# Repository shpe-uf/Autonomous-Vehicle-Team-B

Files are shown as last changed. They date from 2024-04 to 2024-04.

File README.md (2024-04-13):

# Autonomous-Vehicle-Team-B

Introducing our high-performance autonomous RC car, masterfully piloted by the iconic Dominic Toretto. Engineered for versatility, it thrives on diverse terrains with advanced obstacle avoidance, sign detection, and lane keeping. At its core, powerful motors and a sophisticated turning mechanism ensure dynamic mobility, while a 12V battery and Raspberry Pi brain equip it with formidable power and intelligence. This vehicle isn't just about getting from A to B; it's about the journey in between, redefining what it means to drive autonomously.

## Prerequisites

Before you can run this project, you'll need the following installed:

- Python 3.6 or higher
- OpenCV-Python
- picamera2 (specific to Raspberry Pi OS)
- RPi.GPIO (specific to Raspberry Pi)
- asyncio library (should be included with Python 3.6+)

You can install Python from [the official website](https://www.python.org/downloads/).

## Installation

1. **OpenCV-Python**: Install OpenCV for Python by running:

   ```
   pip install opencv-python
   ```

2. **picamera2**: For Raspberry Pi, install the picamera2 library using:

   ```
   sudo apt-get update
   sudo apt-get install python3-picamera2
   ```

3. **RPi.GPIO**: This should come pre-installed with Raspberry Pi OS. If you need to install it, use:

   ```
   sudo apt-get install python3-rpi.gpio
   ```

## Training Cascade Classifiers

Training your own cascade classifiers with OpenCV involves several steps. You will need a set of positive images (images of your object) and negative images (images without your object). Follow these steps:

1. **Collect Images**: Gather a dataset of positive and negative images. Positive images should contain the object you want to detect, and negative images should not.

2. **Annotation**: Use an annotation tool to mark the object in each positive image. One such tool is `labelImg`.

   - Installation: `pip install labelImg`
   - Usage: Run `labelImg`, open your dataset, and start annotating.

3. **Create Samples**: Use OpenCV's `opencv_createsamples` utility to create a vector file from your annotated positive images.

   ```
   opencv_createsamples -info annotations.txt -num 1000 -w 20 -h 20 -vec positives.vec
   ```

4. **Train Cascade**: With the positive vector file and the collection of negative images, you can train the cascade classifier.

   ```
   opencv_traincascade -data cascade_directory -vec positives.vec -bg negatives.txt -numPos 800 -numNeg 400 -numStages 10 -w 20 -h 20
   ```

   Adjust the `numPos`, `numNeg`, and `numStages` parameters based on your dataset.

## Wiring Instructions

The code provided controls a Raspberry Pi-based robot with obstacle detection, line tracking, and basic navigation features. Here's a summary of the wiring based on the GPIO pins defined in your code:

- **Motors**:
  - `motorIn1`, `motorIn2`: Connect to the left motor.
  - `motorIn3`, `motorIn4`: Connect to the right motor.
  - `enL`, `enR`: Connect to the enable pins on your motor driver to control speed.

- **LEDs**:
  - `LEFT`, `RIGHT`: Connect to LEDs that indicate turning direction.

- **Ultrasonic Sensor**:
  - `TRIG`: Connect to the trigger pin.
  - `ECHO`: Connect to the echo pin.

## Project Files Overview

- **`Camera_Drive_Merge.py`**: This is the final competition code and the main file to run everything. It integrates camera-based signal detection with driving functions.
- **`async.py`**: Contains the driving function for the first competition, which is focused on basic driving without camera integration.
- **`signal_detection2.py`**: Used for testing multiple cascades for image detection. It allows you to test the performance of different cascades in recognizing various signals.
- **`signal_detection1.py`**: Designed for testing a single cascade. This script is useful for focused testing on one particular type of signal.
- **XML Files**: These are the cascade files used for image detection. They should be trained as described in the "Training Cascade Classifiers" section and placed in the same directory as your Python scripts for the project.
- **Assembly Mounts**: This folder includes all the 3D-printed mounts designed for securing the vehicle's sensors. It features detailed CAD drawings and specifications essential for proper mount fabrication and sensor integration. 

Please make sure to place all your scripts and XML files in the same directory and run `Camera_Drive_Merge.py` as the main script to start the project.

## Advice for Future Teams

### Asynchronous Programming
Incorporate asynchronous programming to manage concurrent tasks such as sensor readings and motor control. Understanding and using Python's `asyncio` library can significantly enhance the efficiency of your code.

### GPIO and Hardware Interfacing
Gain a clear understanding of Raspberry Pi's GPIO for connecting components like motors and sensors. Ensure correct setup and initialization to avoid unexpected behavior or damage.

### Sensor Integration
Properly integrate and process data from sensors like ultrasonic and line tracking sensors. Implementing filtering and debouncing can improve the reliability of sensor data interpretation.

## Our Trials and Tribulations

### Prototyping Delays
Our project faced setbacks due to delays in 3D printing components, which hindered the coding team's ability to test and debug the system. Future teams should aim to have prototypes ready early on, allowing for simultaneous development and testing by both the mechanical and coding teams. Temporary mounts can be invaluable for this iterative testing process.

### Hardware Challenges
We encountered a significant issue when our camera unexpectedly short-circuited, which went unnoticed until our second competition. This underscored the importance of thoroughly testing each hardware component independently to ensure they are functioning correctly. Pay attention to signs of malfunction, such as components running hotter than usual, which could indicate underlying problems.

### Communication and Commitment
Despite the challenges we faced, strong communication and dedication among team members were key to navigating through difficulties. It's crucial to remain committed and work collaboratively, especially when encountering obstacles. Our ability to stay devoted and allocate the necessary time to address issues played a significant role in overcoming the hurdles we encountered.

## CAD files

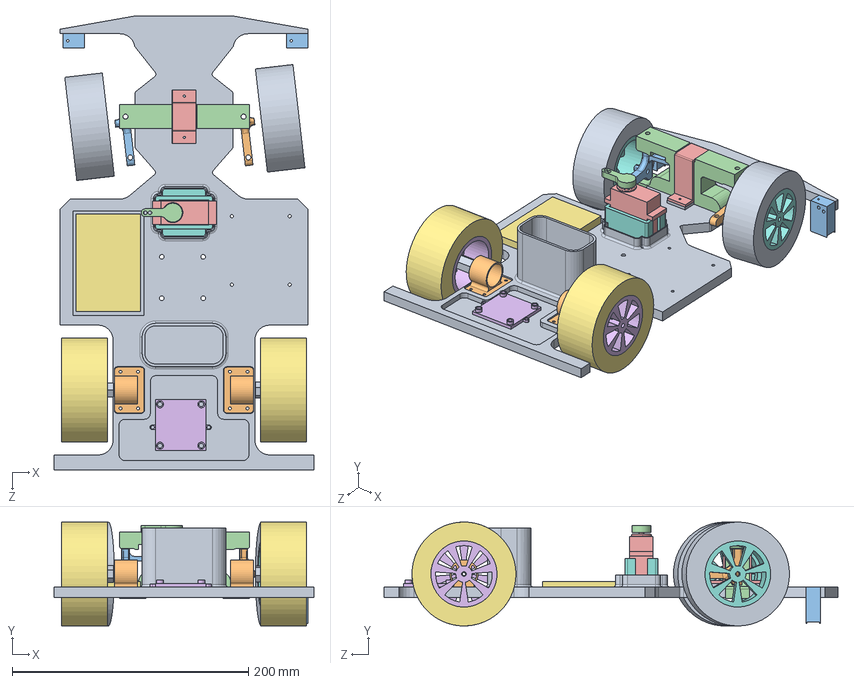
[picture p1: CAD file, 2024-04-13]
Assembly Mounts/Assembly 2.SLDASM
220.0 x 88.0 x 384.4 mm
Frame #2
Servo Motor
Breadboard
motor driver mount
ClampsReal
Steering Frame
Wheel Pivot (With mount)
Wheel Pivot (without mount)
FrontTireSimple x 2
FrontWheelSimple x 2
RearTireSimple x 2
RearWheelSimple x 2
Copy of Servo Motor
Directional pivot (1)
marley.mount.IR_sensor (1) x 2
DC w torque motor mount x 2
wheel rod with torque x 2

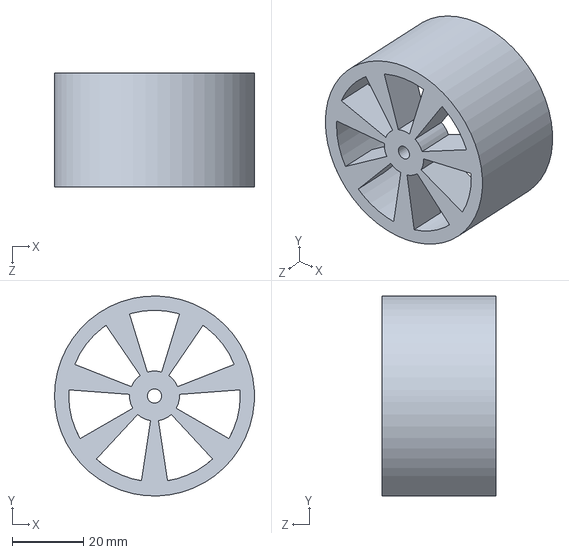
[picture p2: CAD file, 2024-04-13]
Assembly Mounts/FrontWheelSimple.SLDPRT
56.0 x 56.0 x 32.0 mm

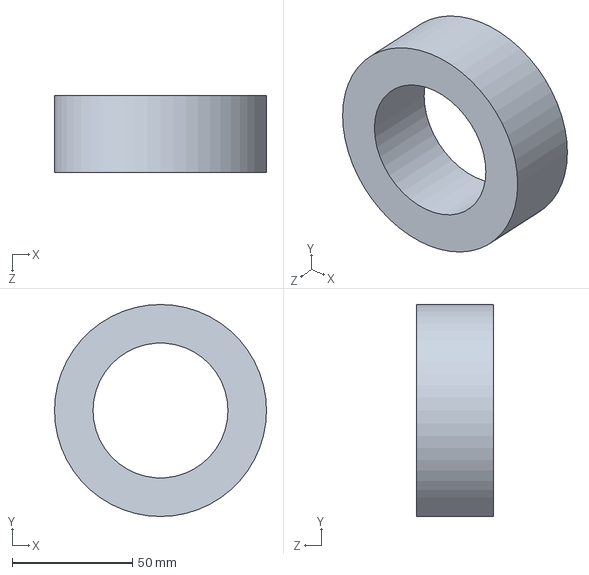
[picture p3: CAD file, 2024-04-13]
Assembly Mounts/FrontTireSimple.SLDPRT
88.0 x 88.0 x 32.0 mm

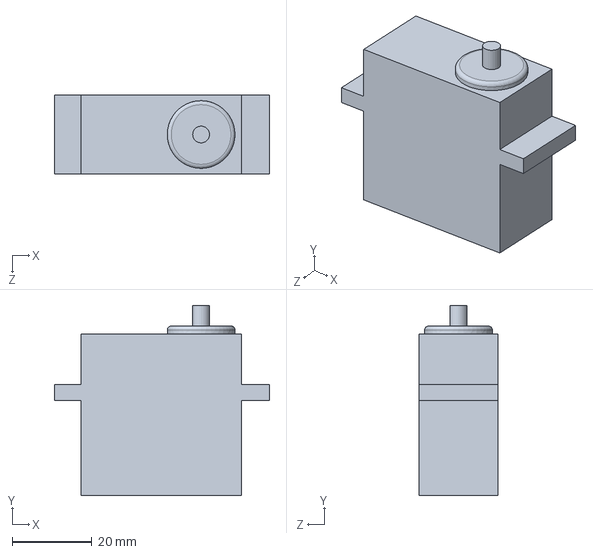
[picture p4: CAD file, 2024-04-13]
Assembly Mounts/Copy of Servo Motor.SLDPRT
54.0 x 47.8 x 19.8 mm

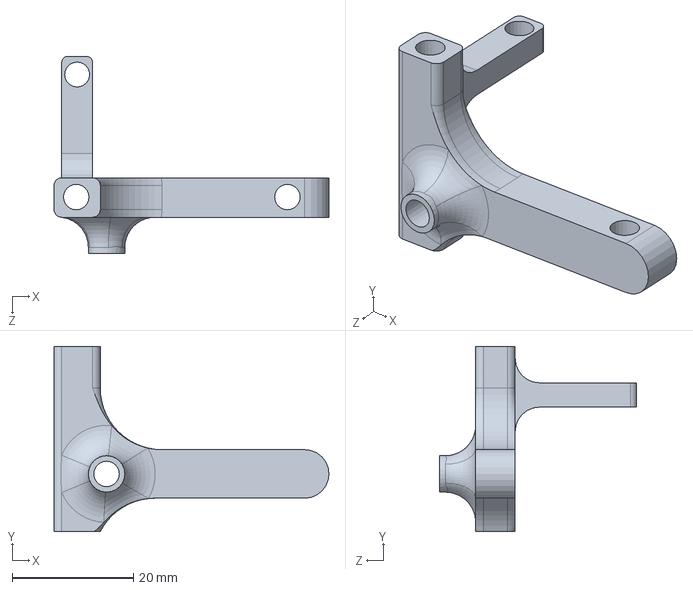
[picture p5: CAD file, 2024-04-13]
Assembly Mounts/Wheel Pivot (With mount).SLDPRT
45.3 x 30.5 x 32.5 mm

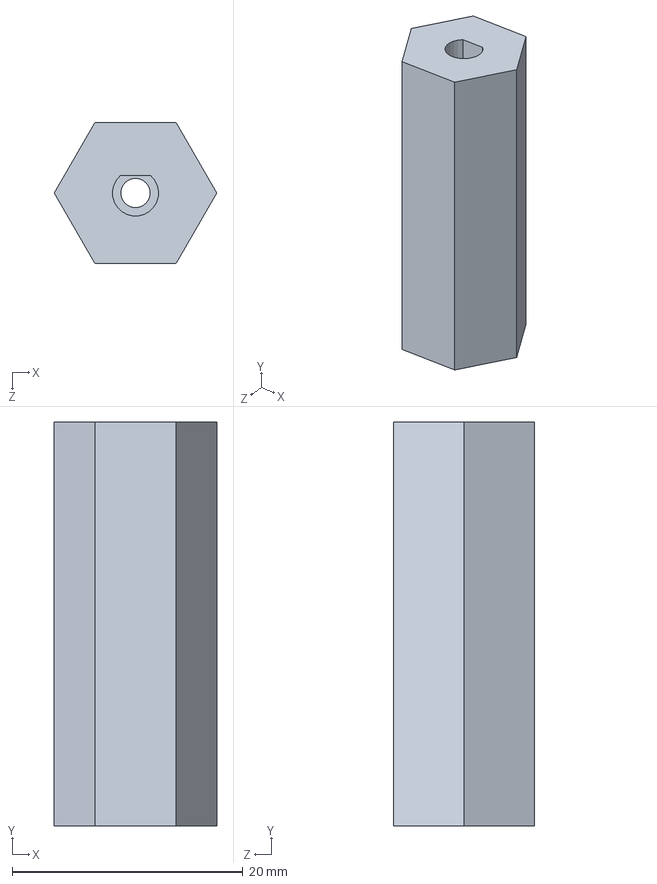
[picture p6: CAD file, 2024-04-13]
Assembly Mounts/wheel rod with torque.SLDPRT
14.1 x 35.0 x 12.2 mm

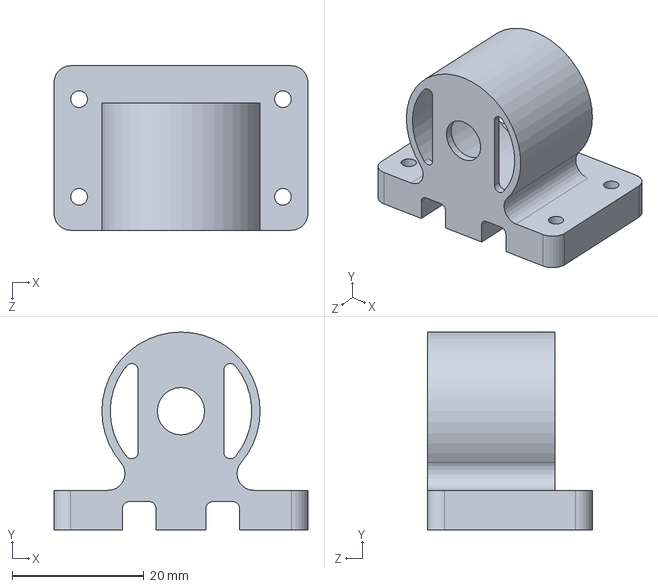
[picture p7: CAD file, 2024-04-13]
Assembly Mounts/DC w torque motor mount.SLDPRT
38.6 x 30.1 x 25.0 mm

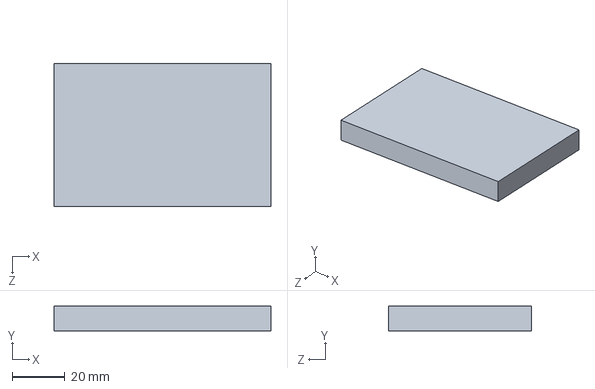
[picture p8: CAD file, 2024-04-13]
Assembly Mounts/Breadboard.SLDPRT
82.5 x 9.50 x 54.2 mm

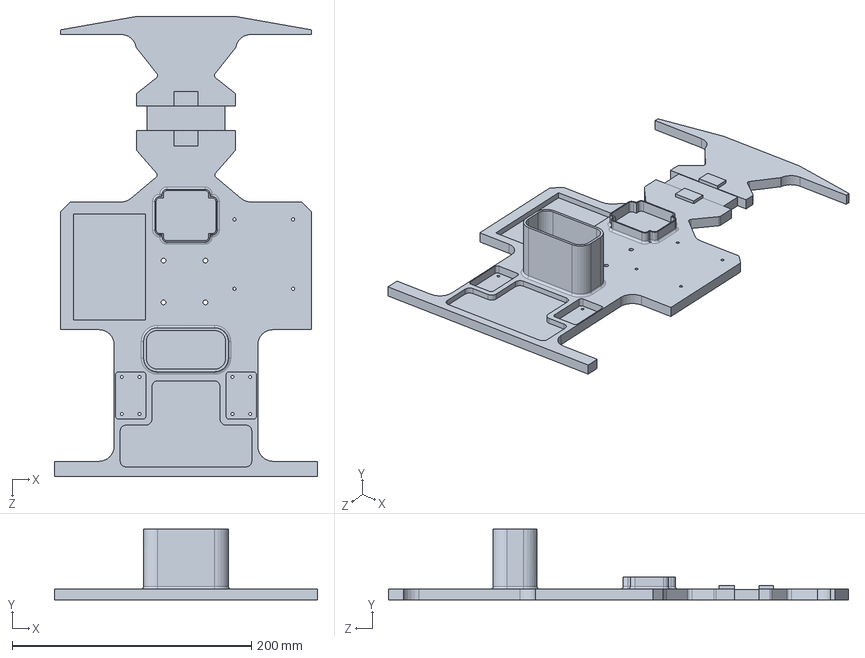
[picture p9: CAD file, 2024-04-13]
Assembly Mounts/Frame #2.SLDPRT
220.0 x 59.1 x 384.4 mm

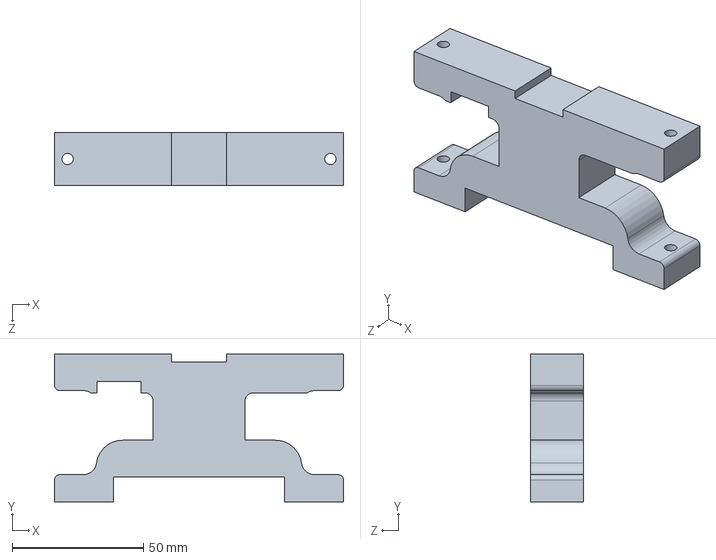
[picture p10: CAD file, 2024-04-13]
Assembly Mounts/Steering Frame.SLDPRT
110.0 x 56.2 x 20.2 mm

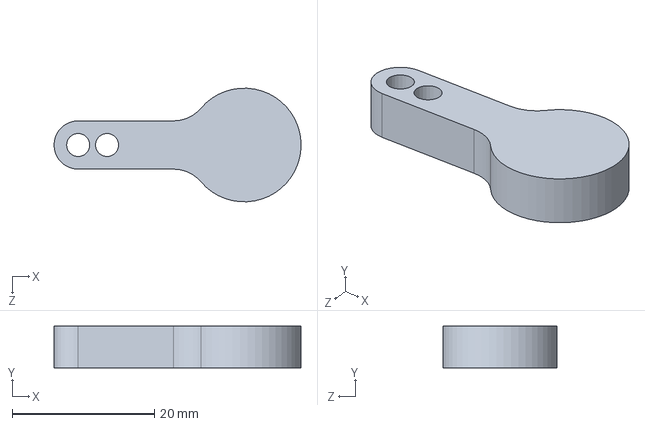
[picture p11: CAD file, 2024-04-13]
Assembly Mounts/Directional pivot (1).SLDPRT
34.8 x 5.84 x 16.0 mm

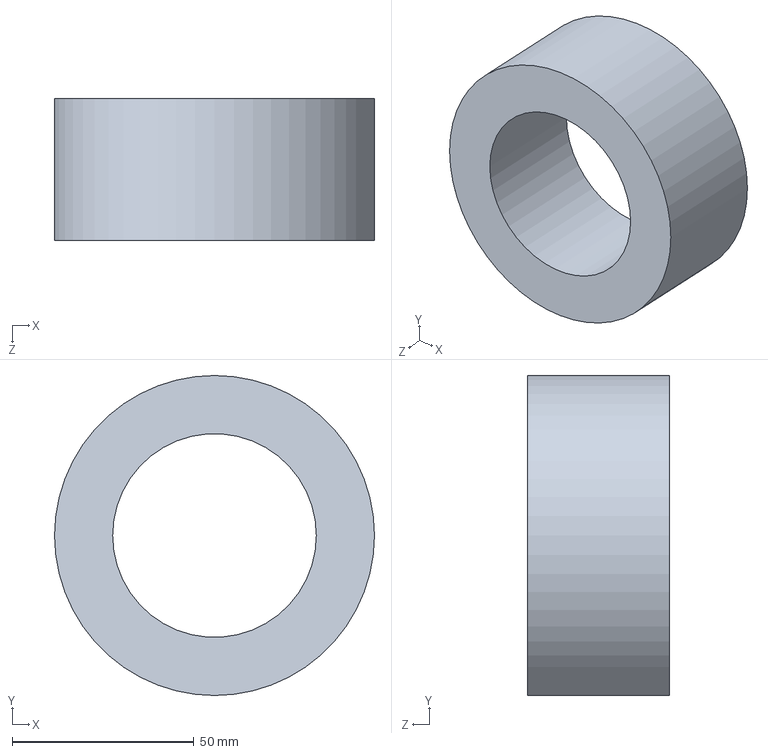
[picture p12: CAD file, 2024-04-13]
Assembly Mounts/RearTireSimple.SLDPRT
88.0 x 88.0 x 39.0 mm

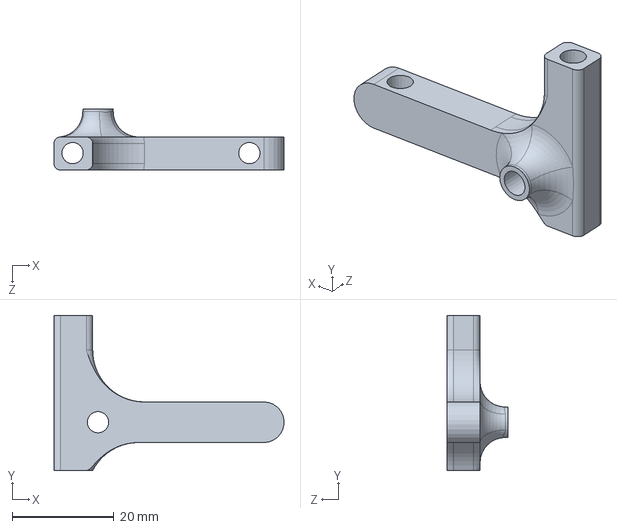
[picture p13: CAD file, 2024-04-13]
Assembly Mounts/Wheel Pivot (without mount).SLDPRT
45.2 x 30.5 x 12.0 mm

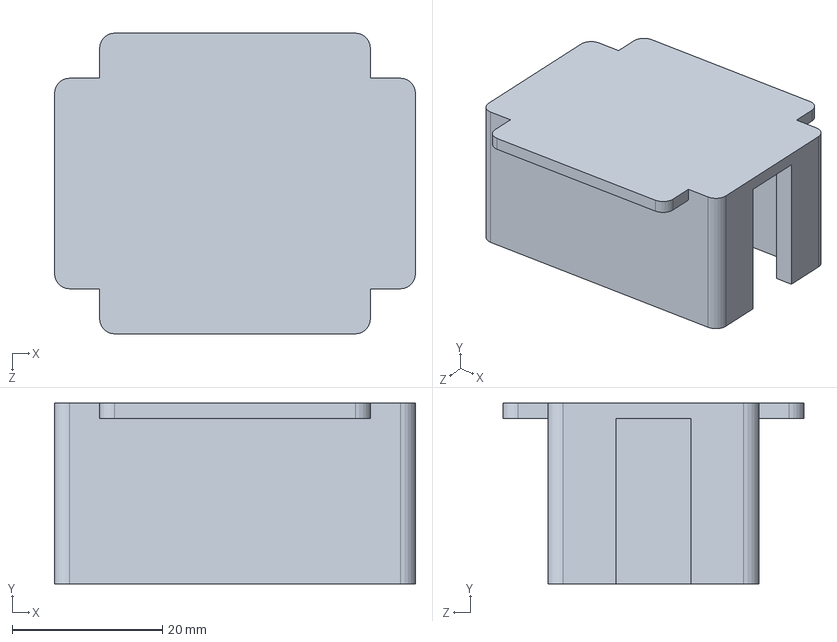
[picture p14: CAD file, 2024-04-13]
Assembly Mounts/Servo Motor.SLDPRT
48.0 x 24.0 x 40.0 mm

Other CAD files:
Assembly Mounts/marley.mount.IR_sensor (1).SLDPRT
Assembly Mounts/motor driver mount.SLDPRT
Assembly Mounts/RearWheelSimple.SLDPRT
Assembly Mounts/ClampsReal.SLDPRT
Assembly Mounts/Battery Pack.SLDPRT
Assembly Mounts/Screw 100mm.SLDPRT
Assembly Mounts/Servo Connection Rod.SLDPRT
Assembly Mounts/Steer Rod.SLDPRT
Assembly Mounts/design team raspberry pi casing.SLDPRT
Assembly Mounts/front wheel hexagon (1).SLDPRT
Assembly Mounts/pi camera mount new.SLDPRT

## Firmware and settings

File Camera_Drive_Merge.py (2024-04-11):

import cv2
import asyncio
import time
from picamera2 import Picamera2
import RPi.GPIO as GPIO

# Set GPIO mode to BOARD
GPIO.setmode(GPIO.BOARD)

# Pin Definitions
LEFT = 3  # Left indicator LED
RIGHT = 5  # Right indicator LED
TRIG = 8  # Ultrasonic sensor trigger pin
ECHO = 7  # Ultrasonic sensor echo pin
motorIn1 = 37  # Left motor input 1
motorIn2 = 40  # Left motor input 2
enL = 33  # Left motor enable pin
motorIn3 = 35  # Right motor input 1
motorIn4 = 36  # Right motor input 2
enR = 38  # Right motor enable pin
SERVO = 32  # Servo motor control pin

# Initialize GPIO pins
GPIO.setup([motorIn1, motorIn2, motorIn3, motorIn4, enL, enR, LEFT, RIGHT, TRIG, SERVO], GPIO.OUT)
GPIO.setup([ECHO], GPIO.IN)

# Set initial state of pins
GPIO.output([motorIn1, motorIn2, motorIn3, motorIn4, LEFT, RIGHT, TRIG], GPIO.LOW)

# Setup PWM for motors and servo
pL = GPIO.PWM(enL, 1000)  # Left motor PWM
pR = GPIO.PWM(enR, 1000)  # Right motor PWM
servo = GPIO.PWM(SERVO, 50)  # Servo PWM (50Hz for servo control)

# Start PWM with initial duty cycle
pL.start(25)
pR.start(25)
servo.start(0)  # Initialize servo position

# Initialize camera
picam2 = Picamera2()
picam2.configure(picam2.create_preview_configuration(main={"format": 'XRGB8888', "size": (640, 480)}))
picam2.start()

# Load cascade classifiers for sign detection
face_cascades = {
    "right": cv2.CascadeClassifier("cascade_right.xml"),
    "left": cv2.CascadeClassifier("leftOld.xml"),
    "stopsign": cv2.CascadeClassifier("stop_OG.xml")
}

# Detect objects asynchronously
async def detect_objects():
    global detected_sign  # Track detected signs globally
    servo.ChangeDutyCycle(7.5)  # Center servo initially

    detection_counter = 0  # Counter for consecutive detections
    no_sign_counter = 0  # Counter for non-detections
    DEBOUNCE_THRESHOLD = 7  # Required consecutive detections to act

    try:
        while True:
            image = picam2.capture_array()  # Capture image from camera
            gray_image = cv2.cvtColor(image, cv2.COLOR_BGR2GRAY)  # Convert to grayscale for detection

            # Initialize detection dict
            detections = {"right": [], "left": [], "stopsign": []}
            sign_detected = False

            # Loop through each cascade to detect signs
            for direction, cascade in face_cascades.items():
                detections[direction] = cascade.detectMultiScale(gray_image, 1.1, 5)
                if detections[direction]:
                    detected_sign = direction
                    sign_detected = True

                    # Perform actions based on detected sign and debounce count
                    if detected_sign == "stopsign" and detection_counter >= DEBOUNCE_THRESHOLD:
                        await STOP()  # Stop if stop sign detected after sufficient debouncing
                        detection_counter = 0  # Reset counter after action

                    elif detected_sign == "left" and detection_counter >= DEBOUNCE_THRESHOLD:
                        # Turn left if left sign detected after sufficient debouncing
                        GPIO.output(LEFT, GPIO.HIGH)
                        servo.ChangeDutyCycle(6.5)  # Adjust servo for left turn
                        await asyncio.sleep(0.5)  # Wait for turn to complete
                        GPIO.output(LEFT, GPIO.LOW)
                        
                    elif detected_sign == "right" and detection_counter >= DEBOUNCE_THRESHOLD:
                        # Turn right if right sign detected after sufficient debouncing
                        GPIO.output(RIGHT, GPIO.HIGH)
                        servo.ChangeDutyCycle(8.5)  # Adjust servo for right turn
                        await asyncio.sleep(0.5)  # Wait for turn to complete
                        GPIO.output(RIGHT, GPIO.LOW)

            # Update counters based on detection
            detection_counter = detection_counter + 1 if sign_detected else 0
            no_sign_counter = no_sign_counter + 1 if not sign_detected else 0

            # Default forward motion if no sign detected for a while
            if no_sign_counter >= DEBOUNCE_THRESHOLD:
                await FORWARD()
                no_sign_counter = 0

            # Distance measurement logic
            global dist
            # Trigger ultrasonic sensor
            GPIO.output(TRIG, True)
            await asyncio.sleep(0.000001)
            GPIO.output(TRIG, False)

            # Measure echo time
            while GPIO.input(ECHO) == 0: pass
            start_time = time.time()
            while GPIO.input(ECHO) == 1: pass
            stop_time = time.time()

            # Calculate distance
            dist = (stop_time - start_time) * 17000

            # Stop if an obstacle is too close
            if dist <= 10:
                await STOP()
                
            # Highlight detected signs in the output video
            for direction, faces in detections.items():
                for (x, y, w, h) in faces:
                    cv2.rectangle(image, (x, y), (x + w, y + h), (0, 255, 0), 2)
                    cv2.putText(image, direction, (x, y - 10), cv2.FONT_HERSHEY_SIMPLEX, 0.9, (0, 255, 0), 2)

            # Show the processed video output
            cv2.imshow("Camera", image)

            # Break the loop with 'q' key
            if cv2.waitKey(1) & 0xFF == ord('q'):
                break

    finally:
        # Clean up
        picam2.stop()
        cv2.destroyAllWindows()

# Function to move the car forward
async def FORWARD():
    # Activate motors for forward motion
    GPIO.output(motorIn1, GPIO.HIGH)
    GPIO.output(motorIn2, GPIO.LOW)
    GPIO.output(motorIn3, GPIO.HIGH)
    GPIO.output(motorIn4, GPIO.LOW)
    pL.ChangeDutyCycle(25)  # Set speed
    pR.ChangeDutyCycle(25)
    
# Function to stop the car
async def STOP():
    # Deactivate all motors
    GPIO.output([motorIn1, motorIn2, motorIn3, motorIn4], GPIO.LOW)
    # Briefly flash LEDs to indicate stopping
    GPIO.output([LEFT, RIGHT], GPIO.HIGH)
    await asyncio.sleep(0.5)
    GPIO.output([LEFT, RIGHT], GPIO.LOW)
    await asyncio.sleep(0.5)
    
# Main function combining driving logic and object detection
async def main():
    await detect_objects()

# Execute main function
if __name__ == "__main__":
    asyncio.run(main())

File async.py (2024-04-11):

#pasted
import RPi.GPIO as GPIO
import time
import asyncio
# Setup GPIO mode
GPIO.setmode(GPIO.BOARD)

# Define GPIO pins
LEFT = 3  # Left LED
RIGHT = 5  # Right LED
TRIG = 8
ECHO = 7
motorIn1 = 37  # Left motor
motorIn2 = 40  # Left motor
enL = 33
motorIn3 = 35  # Right motor
motorIn4 = 36  # Right motor
enR = 38
turn_time_delay = 0.3
dist = 0
angle = 2  # This variable is unused in your original code
leftTrack = 10
rightTrack = 12
SERVO = 32  # Servo pin

# Setup GPIO pins
GPIO.setup([motorIn1, motorIn2, motorIn3, motorIn4, enL, enR, LEFT, RIGHT, TRIG, SERVO], GPIO.OUT)
GPIO.setup([ECHO, leftTrack, rightTrack], GPIO.IN)

# Initialize pins to low
GPIO.output([motorIn1, motorIn2, motorIn3, motorIn4, LEFT, RIGHT, TRIG], GPIO.LOW)

# Setup PWM
pL = GPIO.PWM(enL, 1000)
pR = GPIO.PWM(enR, 1000)
servo = GPIO.PWM(SERVO, 50)  # 50Hz for servo

pL.start(100)
pR.start(100)
servo.start(0)  # Initialize servo to 0 degrees

async def ULT_CHECK():
    global dist
    #Check how far ultrasonic sensor is from object
    print("Measuring")
    GPIO.output(TRIG, 1)
    await asyncio.sleep(0.000001)
    GPIO.output(TRIG, 0)
    
    while GPIO.input(ECHO) == 0:
        pass
    start = time.time()
    
    while GPIO.input(ECHO) == 1:
        pass
    stop = time.time()
    dist = int((stop - start) * 17000)
    
    #print(f"start: {start} and stop: {stop}")
    #print(f"distance: {dist}")

async def LINETRACK():
	left_sensor_active = GPIO.input(leftTrack) == 0  # Assuming 0 is black
	right_sensor_active = GPIO.input(rightTrack) == 0  # Assuming 0 is black

	if left_sensor_active and not right_sensor_active:
		# Left sensor on black, right sensor not on black - turn right, speed up left motor, slow down right motor
		print("Adjusting Right")
		GPIO.output(RIGHT, 1)  # Turn RIGHT LED on
		await asyncio.sleep(0.5)

		servo.ChangeDutyCycle(8.5)
		    
		await asyncio.sleep(0.5)
		GPIO.output(RIGHT, 0)  # Turn RIGHT LED off
		await asyncio.sleep(0.5)

	elif not left_sensor_active and right_sensor_active:
		# Right sensor on black, left sensor not on black - turn left, speed up right motor, slow down left motor
		print("Adjusting Left")
		GPIO.output(LEFT, 1)  # Turn LEFT LED on
		# Speed up right motor
		await asyncio.sleep(0.5)

		servo.ChangeDutyCycle(6.5)

		await asyncio.sleep(0.5)
		GPIO.output(LEFT, 0)  # Turn LEFT LED off
		await asyncio.sleep(0.5)

	else:
		# Both sensors not on black - continue moving forward
		pL.ChangeDutyCycle(25)
		pR.ChangeDutyCycle(25)
		GPIO.output(LEFT, 0)  # Ensure LEFT LED is off
		GPIO.output(RIGHT, 0)  # Ensure RIGHT LED is off
		servo.ChangeDutyCycle(7.5)


	await asyncio.sleep(0.1)





async def STOP_AND_WAIT():
    print("STOP")
    # LED stop signal, flashing while stopped
    while dist <= 5:
        await ULT_CHECK()  # Continuously check distance
        GPIO.output(LEFT, 1)
        GPIO.output(RIGHT, 1)
        await asyncio.sleep(0.5)  # Adjust flash speed as necessary
        GPIO.output(LEFT, 0)
        GPIO.output(RIGHT, 0)
        await asyncio.sleep(0.5)  # Adjust flash speed as necessary

async def DRIVE():
    # Start driving the motor

    GPIO.output(motorIn1, GPIO.HIGH)
    GPIO.output(motorIn2, GPIO.LOW)
    GPIO.output(motorIn3, GPIO.HIGH)
    GPIO.output(motorIn4, GPIO.LOW)

    while True:
        await ULT_CHECK()  # Check distance using the ultrasonic sensor
        await LINETRACK()  # Check line tracking sensors and adjust LED

        if dist >= 5:
            # If object is more than 5 units away, keep driving forward
            print('Driving')
            pL.ChangeDutyCycle(25)
            pR.ChangeDutyCycle(25)
            GPIO.output(motorIn1, GPIO.HIGH)
            GPIO.output(motorIn2, GPIO.LOW)
            GPIO.output(motorIn3, GPIO.HIGH)
            GPIO.output(motorIn4, GPIO.LOW)
        else:
            # If object is closer than 5 units, stop
            GPIO.output(motorIn1, GPIO.LOW)
            GPIO.output(motorIn2, GPIO.LOW)
            GPIO.output(motorIn3, GPIO.LOW)
            GPIO.output(motorIn4, GPIO.LOW)
            await STOP_AND_WAIT()
	    



async def main():
    # Main function to execute the driving logic
    await DRIVE()

# Execute the main function
if __name__ == "__main__":
    print('start')
    
    print('running')
    pL.start(25)
    pR.start(25)
   
    asyncio.run(main())
